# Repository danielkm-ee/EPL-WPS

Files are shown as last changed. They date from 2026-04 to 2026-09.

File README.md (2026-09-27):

# Spark EDM: An EDM power supply for hobby CNCs

A high-efficiency power supply unit designed for Electrical Discharge Machining (EDM) applications. The design is based on the Rack Robotics Powercore V3 and owes much to their engineering efforts.

## EPL Contributions

The EPL has reworked a few aspects of the Rack Robotics Powercore V3 for use in it's CNC-Type Wire EDM. Primarily, we've made use of 2.54mm pin headers in place of the spring-based connectors, or Pogo pins, to simplify construction without the enclosure. Other modifications have been made the the firmware project structure, separating sensor drivers, boost converter, fault handling, and other portions of the project into a modular C++ library. We have also implemented a frequency-coded feedback signal for compatibility with encoder and edge counting inputs available on many CNC control boards.

If you would like to explore or purchase the original PowerCore V3, please vist Rack Robotics at
The originial PowerCore V3 Repo
and
Rackrobo.io

# Repository Structure

```
├── docs               - documentation files & repository resources
│   ├── img                - images for README.md's
│   ├── LTSpice            - LTSpice Simulations
│   └── schematics         - pdfs of the schematics
├── firmware           - firmware project and library based on the PicoSDK
│   ├── docs               - docs for the firmware
│   ├── feedback_test      - firmware which outputs a frequency sweep for feedback testing
│   ├── src                - source files for the Spark EDM firmware
│   └── tpl0401b_test      - test firmware for testing the boost module potentiometer
├── hardware           - hardware resources for PCBs and the enclosure
│   ├── CAD                - CAD resources for enclosure design & system documentation
│   ├── circuit-boards     - circuit boards for the Spark EDM
│   └── KiCAD-library      - KiCAD library for the Spark EDM
└── tools              - tools for flashing & communicating with the Spark EDM
```

# Building the EDM Supply
The Spark EDM is not available for purchase through the EPL or any other means, but access to the manufacturing resources are provided for those with experience ordering and building up PCBs through the likes of JLCPCB, Oshpark, or PCBWay.

# LICENSE 
This project is based on Powercore V3 by Rack Robotics, Inc., used under CC BY-NC-SA 4.0.

Original copyright: © 2025 Rack Robotics, Inc.

Modifications and additions by Portland State University Electronics Prototyping Lab (PSU EPL) are also licensed under CC BY-NC-SA 4.0.

## Changes from Original
* Firmare:
    * Migration from Arduino to pure PicoSDK
    * new project structure and firmware documetation
    * frequency-coded feedback signal
    * testing firmware for the tpl10401b
    * tools for flashing and communicating with the device
    * extended command line interface with commands for setting the gap voltage and machining frequency
    * conventionalized responses from the serial interface for debugging
    * modularized library for the various functions of the power supply for extendability
    * fault handler and context management utilities
* Hardware:
    * Replacement of the RackRobotics and PowercoreV3 logo in compliance with copyright restrictions
    * Use of 2.54mm headers in place of spring-loaded connectors for ease of assembly
    * Removal of thermal reliefs on high-current capacitors in the pi-filter and boost converter module
    * Layout changes with larger trace widths for high current lines
    * Adaptations for 2.54mm connectors
    * Edge cutout for Pi Pico micro-USB and testpoints
    * Updated component values for missing JCL & digikey part numbers
* Documentation
    * Updated schematics reflecting changes in PCB implementation
    * Firmware documentation reflecting new library, developers manual, and coding conventions for maintenence and new feature introduction
    * Developer's notes from capstone members at Portland State University

## You are free to:
* Share — copy and redistribute the material in any medium or format
* Adapt — remix, transform, and build upon the material

### Under the following terms:
* **Attribution** — You must give appropriate credit, provide a link to the license, and indicate if changes were made
* **NonCommercial** — You may not use the material for commercial purposes
* **ShareAlike** — If you remix, transform, or build upon the material, you must distribute your contributions under the same license

For the full license text, see: https://creativecommons.org/licenses/by-nc-sa/4.0/

### Notices:
You do not have to comply with the license for elements of the material in the public domain or where your use is permitted by an applicable exception or limitation.

No warranties are given. The license may not give you all of the permissions necessary for your intended use. For example, other rights such as publicity, privacy, or moral rights may limit how you use the material.

For the full license text, see: https://creativecommons.org/licenses/by-nc-sa/4.0/

This includes all hardware designs, firmware, documentation, and associated files in this repository. Commercial use requires explicit written permission from the project maintainers.

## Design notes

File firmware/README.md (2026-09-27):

# Setup
This firmware is a pure C11 library against the Raspberry Pi Pico SDK.
No Arduino-Pico core is required.

## Toolchain (Fedora 43)
```bash
sudo dnf install arm-none-eabi-gcc-cs arm-none-eabi-gcc-cs-c++ \
                 arm-none-eabi-newlib cmake make libusb1-devel
```

## Pico SDK
Install the SDK anywhere; this project assumes `~/.local/share/pico-sdk`.
Initialise its submodules so TinyUSB (and friends) are present:
```bash
git clone https://github.com/raspberrypi/pico-sdk.git ~/.local/share/pico-sdk
cd ~/.local/share/pico-sdk && git submodule update --init
```

## picotool (USB flash + introspection)
The SDK's bundled picotool is built without USB support. Build a
standalone copy once:
```bash
git clone https://github.com/raspberrypi/picotool.git ~/.local/share/picotool-src
cd ~/.local/share/picotool-src && PICO_SDK_PATH=$HOME/.local/share/pico-sdk cmake -B build && make -C build -j
```

For non-root USB access, install the udev rule once:
```bash
sudo cp ~/.local/share/picotool-src/udev/60-picotool.rules /etc/udev/rules.d/
sudo udevadm control --reload && sudo udevadm trigger
```

## Build
```bash
cd firmware && mkdir build && cd build
PICO_SDK_PATH=$HOME/.local/share/pico-sdk cmake .. \
    -Dpicotool_DIR=$HOME/.local/share/picotool-src/install/lib/cmake/picotool
make -j
```
Artifacts land in `firmware/build/`: `epl_wps.elf`, `epl_wps.bin`,
`epl_wps.uf2`.

## Flash
With the Pico held in BOOTSEL (or already running compatible firmware
that exposes the picotool reset interface):
```bash
~/.local/share/picotool-src/build/picotool load -x firmware/build/epl_wps.uf2
```
`-x` reboots into the application after the load completes.

## Connect
The device exposes USB-CDC at `/dev/ttyACM0` (baud rate is irrelevant;
USB-CDC ignores it):
```bash
screen /dev/ttyACM0 115200      # or: minicom -D /dev/ttyACM0 -b 115200
```
Type `HELP` for the command listing, `HELP <cmd>` for usage of one.

# Command Interface
USB-CDC line interface, exact-match dispatch, strict argc validation,
`OK:` / `ERROR:` response prefixes:

| Command | Effect |
|---|---|
| `SEND_TELEMETRY` | Print the multi-line status block immediately |
| `SET_TELEMETRY <on/off>` | Enable or disable the periodic 1 Hz telemetry tick |
| `SET_ALL_PARAMETERS <discharges> <duty> <freq> <init_v>` | Validate against `config.h` SOA limits including computed on/off times, commit and clear `mode_prep_done` so the next OPERATING entry reconfigures PWM |
| `EDGE_DETECTION_MODE` / `EDM_ISOFREQUENCY_MODE` | Disable output stage, switch mode |
| `RESET_DEVICE` | Disable output stage, drain stdio, `watchdog_reboot(0,0,0)` |
| `SET_DPOT <pos>` | Direct DPOT write (development/diagnostic) |
| `READ_HVP_VOLTAGE` | Averaged read of boost output voltage |
| `UPDATE_DPOT_VOLTAGE_TABLE` | Re-run the startup voltage-table sweep |
| `SET_DPOT_FROM_VTABLE <volts>` | Ramp DPOT to closest table entry |
| `SET_FEEDBACK_RATIO <0..1>` | Directly set the EDM_FEEDBACK power ratio (encoded as PWM frequency) (development/diagnostic) |
| `HELP [<command>]` | List all commands, or print full usage for one |

Unknown commands print `ERROR: Unknown command 'X'` followed by the full
HELP listing.

# Theory of Operation

### Hardware overview
The Powercore is a two-phase EDM power supply:
- **High-voltage phase** ignites the discharge across the wire/workpiece gap. A boost-converter module produces 64–100 V DC, set by a TPL0401B digital potentiometer over I2C.
- **High-current phase** delivers the bulk discharge energy through a pi-filter module, drawing directly from the 48 V input (no programmable rail).
- Four MOSFETs are gated by RP2040 PWM: `SW_HIGH_VOLTAGE_PHASE_PIN` and `SW_HIGH_CURRENT_PHASE_PIN` are P-channel (inverted polarity); `SW_ENABLE_PIN` is N-channel; `OUTPUT_OVERCURRENT_SET_PIN` sets the comparator threshold.
- A motion controller (typically LinuxCNC) toggles `EDM_ENABLE_PIN` to request machining and reads back a power-ratio signal on `EDM_FEEDBACK_PIN`, encoded as PWM frequency at a fixed 50% duty cycle (200–400 Hz; see `docs/freq-encoding.md`).
- Three ADC channels: `PMM_ISENSE_PIN` (input current), `OUTPUT_VSENSE_PIN` (output voltage), `OUTPUT_ISENSE_PIN` (output current). Scaling constants live in `config.h`.
- Three fault sources: `PMM_FAULT_PIN`, `BOOST_PGOOD_PIN` (both active-low), `OUTPUT_OVERCURRENT_PIN` (comparator, falling edge).

### Architecture
```
main.c                                int main(void), boot sequence, main loop,
                                      single GPIO IRQ dispatcher
├── config.h                          pin map, hardware constants, SOA limits
└── src/
    ├── types.h                       device_state_t, mode_of_operation_t,
    │                                 fault_type_t, output_params_t, pwm_output_t
    ├── ctx.{h,c}                     main_ctx_t — central runtime state
    ├── sensors.{h,c}                 ADC, calibration, running average, conversions
    ├── pmm.{h,c}                     PMM enable + inrush wait, fault polling
    ├── boost.{h,c}                   DPOT I2C, voltage table, target-voltage ramp
    ├── output.{h,c}                  output-stage PWM + feedback + iso/edge mode bodies
    ├── fault.{h,c}                   pending/active fault, ISR entry points,
    │                                 main-loop dispatch
    └── cmd.{h,c}                     stdio_usb, command parser, telemetry block,
                                      static dispatch table
```

`main.c` owns three things: `g_ctx` (the runtime context), `g_boost_dpot`
(DPOT handle), and `g_boost_cal` (cal table). Every other module is a
singleton with file-static state inside its own `.c`. Cross-module
communication is by passing a `main_ctx_t *` pointer; only ISR-shared
fields are individually `volatile`. See `docs/library-reference.md` for
the full module-by-module API.

### Startup
`main()` brings USB-CDC up first so the rest of boot can log, then
initialises GPIOs, ADC, and the boost DPOT/I2C. It calibrates the
input-current zero offset with the PMM switch off, enables the PMM and
waits out inrush, then calibrates the output-current zero offset. It
registers the single system-wide GPIO IRQ callback and arms the
PMM-fault / boost-PGOOD / overcurrent edge IRQs, holds the HV-only
output stage active to sweep the DPOT and build a voltage cal table,
and trips `HIGH_VOLTAGE_PHASE_SETUP_FAULT` if that table failed to
build or measured above the safe ceiling. Boot ends in `IDLE` (or
`FAULT`, handled by the first main-loop iteration).

### Main loop
Each iteration: service any pending fault first (recoverable faults
block in a retry/recovery loop; non-recoverable ones require
`RESET_DEVICE`); poll for operator commands; run a ~100 Hz housekeeping
tick (input-current sampling, the `EDM_ENABLE_PIN` → state transition,
feedback-ratio update); dispatch the current state (`OPERATING` preps
the active mode lazily then runs its per-tick body, `IDLE` disables the
output stage); send periodic telemetry.

### Operating modes
- **EDM iso-frequency** — constant-frequency discharge generation. The
  output stage pulses the HV and HC phases out of phase to avoid
  shoot-through; each discharge event updates running current/voltage
  averages and a windowed success rate, which can pulse-skip the
  output if discharge success or input power runs too high.
- **Edge-detection** — single-pulse workpiece probing at a fixed low
  duty cycle. The first detected discharge disables the output
  immediately and signals the host with a feedback tone burst.

### Fault model
Three trip sources: PMM fault and boost-PGOOD loss are recoverable and
clear automatically once the condition resolves; HV-setup and
input-power faults are non-recoverable and require `RESET_DEVICE`.
`fault_trip()` always disables the output stage before raising the
pending flag, so the hardware is safe regardless of when the main loop
gets around to handling it.

---

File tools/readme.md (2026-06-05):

# Utilities for the WPS
Here is a place for tools and services built around the Wire Power Supply.

## wps-monitor.py
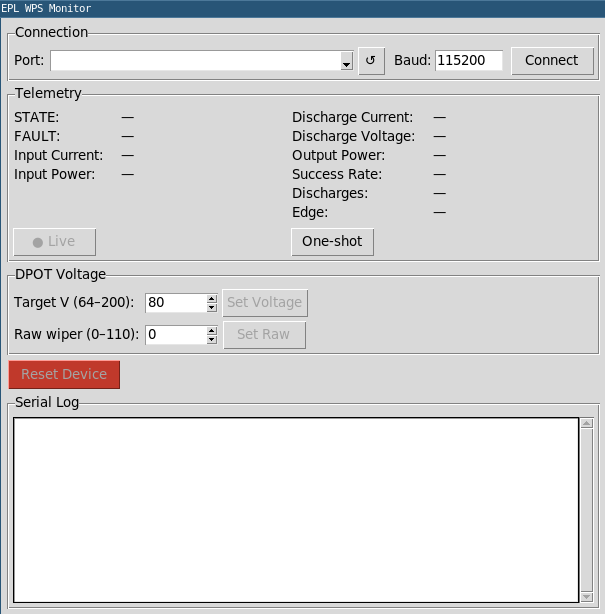
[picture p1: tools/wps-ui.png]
wps ui


This is a GUI for controlling viewing the Wire Power Supply. It includes a serial monitor and controls for setting the output voltage, resetting the device, and connecting to the device. 

> This has been developed in part using Claude 4.6

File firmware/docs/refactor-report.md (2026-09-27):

# Firmware Refactor Report

**Branch:** `firmware-refactor`
**Baseline:** `firmware.ino` — 1530 lines, single file, would not compile
**Result:** `firmware.ino` (336 lines) + 5 modules under `src/` (~900 lines total), clean compile at 74820 B flash / 10244 B RAM

**Goals:** make the firmware compile, fix latent runtime bugs, split into maintainable modules, and remove dead code from a prior hardware revision.

---

## Changelog

### Stage 1 — Bug fixes
- Fixed missing closing brace in `READ_HVP_VOLTAGE()` that caused the entire file to fail parsing
- Renamed `volatile FaultStateType FaultStateType` (variable shadowing its own type) to `currentFaultType`
- Fixed HV fault ISRs acknowledging `BOOST_CONVERTER_PGOOD_FAULT` (a fault enum value, not a GPIO) instead of `BOOST_PGOOD` (GPIO 18) — the interrupt was never actually cleared
- Fixed `sendTelemetry()` always printing `FAULT NONE` due to `isInFaultState` being declared but never assigned; replaced with `deviceState == FAULT`
- Moved all blocking work (`Serial.println`, `delay`, recovery loops) out of ISR context into `fault_handle()` on the main loop; ISRs now only ack the IRQ, disable the output stage, and set a pending flag

### Stage 2 — Extract shared headers
- `config.h`: all pin assignments, hardware constants, scaling factors, and safe-operating limits
- `src/types.h`: all shared enums and structs (`DeviceState`, `ModeOfOperation`, `FaultStateType`, `OutputParameters`, `PWMOutput`)

### Stage 3 — Split into modules

| Module | Responsibility |
|---|---|
| `sensors` | ADC setup, calibration, input-current averaging, ADC→engineering-unit conversions |
| `pwm_control` | EDM-feedback PWM and output-stage PWM setup, safe-OFF disable |
| `boost_module` | TPL0401B DPOT over I2C, voltage lookup table, `boost_set_voltage` ramping |
| `fault_handler` | Fault state, ISR registration, main-loop `fault_handle()` dispatcher |
| `telemetry` | Serial lifecycle, command parser, telemetry formatter, parameter validation |

### Stage 4 — Remove dead code (buck-converter era)
- Removed `BUCK_POWER_GOOD`, `BUCK_ENABLE`, `BUCK_ADJ_PWM` pin definitions and their `setup()` configuration (buck stage replaced by pi-filter board)
- Removed `BUCK_CONVERTER_PGOOD_FAULT` enum and its dead ISR
- Removed `PMM_FAULT_IN_USE`, `HIGH_CURRENT_PGOOD_IN_USE`, `HIGH_VOLTAGE_PGOOD_IN_USE` flags (all were compile-time constants); replaced conditional ISR registration with unconditional attaches
- Removed unused `pmm_recovered()` helper
- Removed duplicate `gpio_set_function(..., GPIO_FUNC_PWM)` calls
- Promoted two magic numbers to named `config.h` constants

### Stage 5 — Simplify state machine
- Removed `PERIPHERAL_MANAGEMENT` device state; periodic work is now an unconditional timed call from `loop()`
- Removed `oldDeviceState` shadow; post-fault recovery sets `deviceState = IDLE` and the next peripheral tick re-derives `OPERATING`/`IDLE` from `EDM_ENABLE`
- Removed global `currentFaultType`; owned internally by `fault_handler`, queried via `fault_current_type()`
- Inlined `enablePortStatus` global flag into a direct `digitalRead(EDM_ENABLE)` at the call site

---

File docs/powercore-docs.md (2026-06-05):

## Table of Contents

- [PSU HIGHLIGHTS](#psu-highlights)
- [FEATURES](#features)
- [APPLICATIONS](#applications)
- [GENERAL DESCRIPTION](#general-description)
- [SPECIFICATIONS](#specifications)
- [Recommended Operating Conditions](#recommended-operating-conditions)
- [DEVICE INTERFACES](#device-interfaces)
  - [Power Input Connector](#power-input-connector)
  - [Power Output Connector](#power-output-connector)
  - [Digital Interface Connector](#digital-interface-connector)
  - [USB-Micro Serial Interface](#usb-micro-serial-interface)
- [THEORY OF OPERATION](#theory-of-operation)
- [OPERATION MODES](#operation-modes)
  - [Startup Behavior](#startup-behavior)
  - [Idle Mode](#idle-mode)
  - [Iso-Frequency Mode](#iso-frequency-mode)
  - [Edge-Detection Mode](#edge-detection-mode)
- [APPLICATION EXAMPLE: MINIMUM IMPLEMENTATION](#application-example-minimum-implementation)
- [EMC & EMI](#emc--emi)
- [Images of PCBA](#images-of-pcba)
- [Typical PSU Waveforms](#typical-psu-waveforms)
- [LICENSE](#license)
- [⚠️ HIGH VOLTAGE SAFETY WARNING ⚠️](#️-high-voltage-safety-warning-️)

## PSU HIGHLIGHTS

1. Optimized for wire EDM applications
2. Maximum input power: 300W with high efficiency topology
3. Adjustable output parameters:
   - Machining Duty Cycle: 1% to 10%
   - Spark Initiation Voltage: 64V to 100V
   - Machining Frequency: 5kHz to 10kHz
4. USB serial interface for configuration and telemetry
5. PWM feedback output for external feedrate control
6. Edge detection capability for workpiece probing

Powercore V3 Enclosure View

## FEATURES

- **Dual-Converter Topology** with resonant converter and boost converter for high-efficiency EDM machining
- Input power optimized for desktop/micro-scale wire EDM (300W maximum, 48V input)
- Output parameters configurable via USB-micro serial interface
- Integrated protection features: pulse-skipping, overcurrent protection, and inrush protection
- Open-source electronics, firmware, and CAD files

## APPLICATIONS

- Wire EDM
- Plunge EDM
- Desktop-scale EDM machines
- Portable and battery-powered EDM machines
- Scientific research and development

## GENERAL DESCRIPTION

The Powercore V3 provides precision control of machining parameters including duty cycle, spark initiation voltage, and machining frequency. The system is optimized for desktop-scale wire EDM applications. The open-source design enables customization for research, development, and specialized EDM implementations.

## SPECIFICATIONS

| SPECIFICATION | Min | Max Value | UNIT |
| --- | --- | --- | --- |
| Average Input Power | 10 | 300 | W |
| Input Voltage | 47.8 | 48.2 | V |
| Input Current | 0.625 | 6.25 | A |
| Machining Duty Cycle | 1 | 10 | % |
| Spark Initiation Voltage | 64 | 100 | V |
| Machining Frequency | 5,000 | 10,000 | Hz |
| Machining Current (1) | 40 | 70 | A |
| PWM Feedback Duty Cycle | 0 | 100 | % |
| PWM Feedback Voltage | 0 | 3.3 | V |
| PWM Feedback Frequency  | — | 1,000 | Hz |
| PWM Feedback Output Impedance | 1,010 | 9,990 | Ω |
| Enable Input Voltage | 3.0 | 3.5 | V |
| Enable Input Impedance | 1,010 | 9,990 | Ω |

(1) Machining current depends on output cable impedance and discharge characteristics. Not regulated by constant-current control. Lower-impedance output cables provide higher machining current.

## Recommended Operating Conditions

| Parameter | Value |
| --- | --- |
| Ambient Temperature | 0°C to 30°C |
| Ingress Protection Rating | IP20 (Indoor use) |
| Relative Humidity | 20% to 80% (non-condensing) |
| Input Cable Gauge | 16 AWG minimum |
| Output Cable Gauge | 16 AWG stranded, 300V rated |
| Output Cable Length | <1 meter, twisted pair |
| Cooling | Forced air cooling recommended |

## DEVICE INTERFACES

Powercore V3 Device Interface Diagram

### POWER INPUT CONNECTOR

Input power connects via 2-position lever-action Wago connector accepting 16 AWG conductors. 48VDC input must be connected before applying 5V via USB-micro. If USB power is applied before 48VDC input, the microcontroller enters fault mode.

### POWER OUTPUT CONNECTOR 

Output connects via 2-position lever-action Wago connector accepting 16 AWG stranded conductors. Output cable must be twisted pair, <1 meter length, and either shielded/grounded or contained within a shielded/grounded enclosure.

### DIGITAL INTERFACE CONNECTOR 

4-position JST-XH header provides communication with external controllers. Exposes 3.3V and GND from RP2040 microcontroller with current-limiting resistors.

- **Enable Input**: Output is enabled when this input is connected to 3.3V or external 3.3V supply with common ground. 10kΩ pull-down resistor to GND.
- **Feedback Output**: Reports EDM power consumption via active-low PWM signal. 100% duty cycle indicates no power consumption from machining; 0% indicates short circuit. Maintain 10-90% duty cycle during machining by adjusting feedrate. 10kΩ pull-down resistor to GND. External low-pass filter can convert to analog feedback.

### USB-MICRO SERIAL INTERFACE

Exposes USB-micro connector of RP2040 Pico module for parameter configuration and telemetry. Default baud rate: 115,200.

**Warning**: Device requires both 48VDC input power AND 5V USB power. 48VDC must be connected first, or device enters fault mode.

| SERIAL COMMAND | DESCRIPTION |
| --- | --- |
| SEND_TELEMETRY | Request device status and parameters |
| SET_ALL_PARAMETERS | Configure machining parameters: discharges, duty cycle, frequency, initiation voltage<br>Format: 'SET_ALL_PARAMETERS [discharges] [duty_cycle] [frequency] [voltage]'<br>Example: 'SET_ALL_PARAMETERS 0 0.10 5000 100' |
| EDM_ISOFREQUENCY_MODE | Enter EDM iso-frequency mode |
| EDGE_DETECTION_MODE | Enter edge detection mode |
| RESET_DEVICE | Reset device |

Invalid commands return list of valid commands.

## THEORY OF OPERATION

The Powercore V3 generates controlled electrical discharges for EDM machining. The system cycles through spark initiation, current delivery, and discharge termination at high frequency (5-20kHz).

**Spark Initiation Voltage**: Determines spark formation conditions. Higher voltages create longer, more intense discharges suitable for harder materials.

**Machining Duty Cycle**: Controls discharge duration. Longer duty cycles increase material removal rate but may increase surface roughness.

**Machining Frequency**: Sets discharge repetition rate. Lower frequencies can increase material removal rate but may reduce surface finish quality.

**Machining Current**: Ranges from 40A to 70A, determined by fixed 48VDC output during current phase and combined impedance of output cables and discharge gap. Current is not user-adjustable.

## OPERATION MODES

### STARTUP BEHAVIOR 

On power-up, output is disabled (high-impedance state). Power management module initializes and pi-filter capacitors charge to 48V with inrush protection. Brief audible noise (~1 second) is normal during startup. Output current sensor calibrates and serial communication establishes.

**BOOST CONVERTER SELF-TEST**: System tests boost converter module and I2C digital potentiometer. If I2C communication fails, device reports 'ERROR: DPOT is not at expected position'. 

During startup, digital potentiometer cycles through settings 0-110, generating boost converter output voltage lookup table (50V-160V). If voltage range is insufficient, device enters fault mode and reports 'ERROR: DPOT voltage range is less than expected'.

Normal startup sequence via serial:
```
Setting DPOT to minimum position...
Waiting for voltage to stabilize...
Reading voltages for DPOT lookup table...
Boost Converter Digital Potentiometer Voltage Table:
0: 51
1: 52
...
109: 161
110: 166
```

Successful startup indicated by solid green LED and "Setup complete" message. Device enters IDLE mode.

### IDLE MODE

Output remains in high-impedance state until enable input is asserted (3.3V). No discharges occur in idle mode.

### ISO-FREQUENCY MODE

Fixed-frequency discharge mode. Default mode or activated via 'EDM_ISOFREQUENCY_MODE' command. Enable input must be asserted (3.3V) to begin operation.

**ISO-FREQUENCY MODE PARAMETERS**

| PARAMETER | Min | Default | Max | Unit |
| --- | --- | --- | --- | --- |
| Machining Duty Cycle | 1 | 10 | 10 | % |
| Machining Frequency | 5,000 | 1,000 | 10,000 | Hz |
| Spark Initiation Voltage | 64 | 80 | 100 | V |

### EDGE-DETECTION MODE

Probe mode for detecting electrode-workpiece contact via PWM feedback. Intended for setup and calibration only, not for machining. Activated via 'EDGE_DETECTION_MODE' command with enable input asserted.

## APPLICATION EXAMPLE: MINIMUM IMPLEMENTATION

Powercore V3 Minimum Implementation

Minimum system configuration:

| Connection | Requirements |
| --- | --- |
| Power Input | 48V, 300W supply via 16 AWG stranded wire |
| USB-Micro | 5V supply or PC connection. **Note**: 48V must be connected first |
| Enable Input | Connect to 3.3V after power supplies are connected |
| Power Output | Positive (+) to workpiece, negative (-) to electrode (wire/tool) |

## EMC & EMI

The Powercore V3 power supply unit is housed in a precision-machined, billet-aluminum enclosure, fully grounded to minimize electromagnetic interference. When no output cables are connected, radiated emissions are negligible. However, when output cables are attached, radiated emissions vary based on cable characteristics, including length, twist, and wire gauge.

**Requirements**: Output cables must be shielded, grounded, and twisted. Poor cable design may increase emissions and interfere with sensitive equipment.

**Installation**: Complete machining setup should be enclosed, shielded, and grounded. EMC compliance is installer's responsibility.

## Images of PCBA

### PCBA View 1
Powercore V3 PCBA View 1

### PCBA View 2
Powercore V3 PCBA View 2

### PCBA View 3
Powercore V3 PCBA View 3

### PCBA View 4
Powercore V3 PCBA View 4

## Typical PSU Waveforms

### Output Stage Switch Control
Normal behavior of output stage switches during EDM iso-frequency mode. The enable (yellow trace) and high-current phase (red trace) switches are both active at the same time, permitting current flow from the positive electrode to the negative electrode. The high-voltage switch is active several microseconds before each switching event, for the purpose of charging the output capacitor to the spark initiation voltage (blue trace).

Powercore V3 Waveform 1

### Gap Voltage with Electrodes Separated
Normal behavior of output stages during EDM iso-frequency mode, with the electrodes separated by several millimeters under distilled water. The positive (+) electrode (red trace) shows the change in gap voltage when the output capacitor is charged and then slowly discharged through the water.

Powercore V3 Waveform 2

### EDM Discharge Behavior
Normal behavior of output stages during EDM iso-frequency mode, during electrical discharge machining. The positive (+) electrode voltage changes rapidly during an EDM discharge; transitioning from the spark initiation voltage (here 80V) to the gap machining voltage (~40V) in several hundred nanoseconds.

Powercore V3 Waveform 3

Powercore V3 Waveform 4

### Boost Converter Operation
Normal behavior of the boost converter module. The MOSFET gate (blue trace) presents with short pulses, which are used to maintain a stable output voltage. The output voltage will be set by the I2C digital potentiometer to between 64 and 150 V.

Powercore V3 Waveform 5

Startup behavior of device. Two seconds are required for inrush protection and serial communication initiation. Subsequently, the boost converter and output voltage sensor collaborate to create the lookup table for the I2C digital potentiometer. Once the lookup table is constructed, the boost converter is set to its default 80V setting.

Powercore V3 Waveform 5

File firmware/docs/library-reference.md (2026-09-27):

# EPL Spark EDM Firmware — Library Reference

This document describes the modules under `firmware/src/` that together
implement the EPL Wire EDM Power Supply firmware. It is intended for a
developer who has just joined the project and wants to understand what
each module owns, how state is partitioned, and where to look when
adding a feature.

The firmware is **pure C11 against the Raspberry Pi Pico SDK**.

For setup, the build, the USB-CDC command table, and a short theory of
operation see `firmware/README.md` — this document does not repeat
that material. For the *why* behind the current shape see
`refactor-report.md`. For pin-level and electrical detail see
`config.h` and the schematics under `docs/schematics/`.

---

## 1. Architecture at a glance

```
            ┌───────────────────────────────────────────────┐
            │  main.c — boot sequence, main loop,           │
            │           single GPIO IRQ dispatcher          │
            └────────┬─────────────┬─────────────┬──────────┘
                     │             │             │
                     ▼             ▼             ▼
                 ┌───────┐    ┌────────┐    ┌────────┐
                 │  cmd  │    │ fault  │    │  ctx   │
                 │ (USB- │    │ (latch │    │ (state │
                 │  CDC) │◄───┤ + spin │    │  hub)  │
                 └───┬───┘    │  loop) │    └────────┘
                     │        └────┬───┘
                     │             │
                     └─────┬───────┘
                           ▼
                       ┌────────┐
                       │ output │  output-stage PWM,
                       │        │  feedback PWM,
                       │        │  iso / edge mode bodies,
                       │        │  overcurrent ISR
                       └───┬────┘
                           │
              ┌────────────┼────────────┐
              ▼            ▼            ▼
          ┌────────┐   ┌────────┐   ┌─────────┐
          │ boost  │   │  pmm   │   │ sensors │
          │ (DPOT/ │   │ (high- │   │  (ADC)  │
          │  I2C)  │   │  side) │   │         │
          └────────┘   └────────┘   └─────────┘

      shared types:        src/types.h
      hardware constants:  config.h
```

Three design rules drive the partitioning:

1. **`main.c` owns boot sequence, main loop, and the system-wide GPIO IRQ
   callback.** It is the only place that holds module-spanning runtime
   state (`g_ctx`, `g_boost_dpot`, `g_boost_cal`).
2. **Each `src/` module is a singleton with file-static state.** No
   transparent structs leak across module boundaries; ownership is
   one-peripheral-one-module. The `output` module is the only writer to
   the output-stage PWM slices; `boost` is the only thing that talks
   I2C to the DPOT; `sensors` is the only ADC consumer.
3. **Cross-module state lives in `main_ctx_t`** (defined in `ctx.h`) and
   is passed by pointer. No `extern` globals. ISR-shared fields are
   individually `volatile`.

Module APIs follow `module_func_desc()` naming. Constants are
`SCREAMING_SNAKE_CASE`. K&R braces.

---

## 2. Build layout

| File | Role |
|---|---|
| `main.c` | `int main(void)` — boot sequence, main loop, GPIO IRQ dispatcher. Owns `g_ctx`, `g_boost_dpot`, `g_boost_cal`. |
| `config.h` | Pin assignments (`*_PIN`), hardware constants, safe-operating limits, feature flags. **No runtime state.** |
| `CMakeLists.txt` | Pico SDK target definition, source list, link libs. |
| `src/types.h` | Shared enums (`device_state_t`, `mode_of_operation_t`, `fault_type_t`) and structs (`output_params_t`, `pwm_output_t`). |
| `src/ctx.{h,c}` | `main_ctx_t` and helpers (`ctx_init`, `ctx_set_state`, `ctx_set_mode`, `ctx_reset_discharge_stats`). |
| `src/sensors.{h,c}` | ADC drivers: PMM input current, output current, output voltage. Owns calibration offsets and the input-current running-average buffer. |
| `src/pmm.{h,c}` | Power-management module: high-side enable, inrush-wait, polled fault read. |
| `src/boost.{h,c}` | I2C driver for the boost-converter's TPL0401B digital potentiometer; owns the DPOT→voltage lookup table. |
| `src/output.{h,c}` | Phase-correct PWM for the four output-stage switches and the EDM_FEEDBACK signal; iso-frequency and edge-detection mode bodies; overcurrent ISR. |
| `src/fault.{h,c}` | ISR-thin / loop-thick fault model. Pending-fault flag, recovery dispatch, three ISR entry points. |
| `src/cmd.{h,c}` | USB-CDC stdio, command parser with static dispatch table, telemetry block. |

---

## 3. Shared types (`src/types.h`)

```c
typedef enum { STARTUP, FAULT, OPERATING, IDLE } device_state_t;

typedef enum { EDM_ISOFREQUENCY_MODE,
               EDGE_DETECTION_MODE } mode_of_operation_t;

typedef enum { PMM_FAULT_TYPE,
               BOOST_CONVERTER_PGOOD_FAULT,
               POWER_OUT_OF_RANGE_FAULT,
               HIGH_VOLTAGE_PHASE_SETUP_FAULT } fault_type_t;

typedef struct {
    int   discharge_count_target;   /* 0 = infinite */
    float duty_cycle;               /* 0.01 .. 0.12 */
    float frequency_hz;             /* 5000 .. 10000 */
    float init_voltage;             /* 64 .. 100 V */
} output_params_t;

typedef struct { uint32_t slice; uint32_t channel; } pwm_output_t;
```

`pwm_output_t` is shared so the output module can describe either of the
two channels (A/B) on a shared RP2040 PWM slice with the same descriptor.
`output_params_t` is the validated payload of `SET_ALL_PARAMETERS` and
the source of truth for live machining parameters (mirrored in
`main_ctx_t::params`).

---

## 4. Central runtime state — `main_ctx_t` (`src/ctx.h`)

```c
typedef struct {
    /* State machine */
    volatile device_state_t      state;
    volatile mode_of_operation_t mode;
    volatile bool                mode_prep_done;

    /* Machining parameters (mutated by SET_ALL_PARAMETERS) */
    volatile output_params_t     params;

    /* EDM iso-frequency discharge statistics (written by output ISR) */
    volatile bool     new_discharge_detected;
    volatile int      new_discharge_current_adc;
    volatile int      new_discharge_voltage_adc;
    volatile double   avg_discharge_current;
    volatile double   avg_discharge_voltage;
    volatile double   avg_discharge_success_rate;
    volatile double   discharge_success_rate;
    volatile int      current_discharge_count;
    volatile int      discharges_since_op_start;
    volatile bool     requested_discharges_reached;
    volatile uint32_t last_success_rate_calc_us;
    volatile int      discharge_rate_calc_interval_us;

    /* Edge-detection mode (written by output ISR) */
    volatile bool edge_detected;

    /* Periodic tick cursors (main loop only; not ISR-shared) */
    uint32_t last_periph_tick_ms;
    uint32_t last_telemetry_tick_ms;

    /* Feature flags (initialised from config.h constants) */
    bool allow_success_rate_pulse_skip;
    bool allow_power_setpoint_pulse_skip;
    bool periodic_telemetry_enabled;
} main_ctx_t;
```

`main.c` declares `static main_ctx_t g_ctx`. Every cross-module function
takes `main_ctx_t *ctx`. `volatile` is on the *fields* the ISRs touch,
not the pointer itself — passing a non-volatile pointer into ISR
context is intentional.

| Function | Effect |
|---|---|
| `ctx_init(ctx)` | Zero everything, set state=STARTUP, default machining params, copy feature flags from `config.h`. |
| `ctx_set_state(ctx, s)` | Direct state assignment. |
| `ctx_set_mode(ctx, m)` | Set mode and clear `mode_prep_done` so the next OPERATING entry re-preps. |
| `ctx_reset_discharge_stats(ctx)` | Clear all discharge-stat fields and `mode_prep_done`. Called by main loop after fault recovery. |

---

## 5. Module reference

### 5.1 `sensors` — ADC drivers

Owns three things:

- **Calibration offsets** for PMM input-current and output-current
  sensors. Captured at boot with no load on the sensor; subtracted from
  every subsequent ADC reading so 0 A reads as 0 A.
- **Input-current running-average buffer**
  (`DEVICE_CURRENT_BUFFER_SIZE = 100` samples). Filled by
  `sensors_sample_input_current()` once per peripheral-management tick
  (~10 ms) and read by the safety check and by telemetry.
- **Pure conversion helpers** for discharge ADC values captured inside
  the output-overcurrent ISR.

```c
void  sensors_init(void);
void  sensors_calibrate_input_current(void);   /* blocking, no-load */
void  sensors_calibrate_output_current(void);  /* blocking, no-load */

void  sensors_sample_input_current(void);
float sensors_avg_input_current_amps(void);
float sensors_read_output_voltage_averaged(int samples);

/* ISR fast paths */
int   sensors_read_output_current_adc(void);
int   sensors_read_output_voltage_adc(void);
float sensors_adc_to_discharge_current_amps(int adc);
float sensors_adc_to_discharge_voltage_volts(int adc);
```

ADC channel mapping is implicit in pin assignments: GPIO 26 = ADC0,
27 = ADC1, 28 = ADC2. Internally, every read does
`adc_select_input(pin - 26); adc_read()`.

Calibration order matters: PMM zero is taken with the high-side switch
*off*, then the switch is enabled and output-current zero is taken.
`main()` does this in the correct order.

### 5.2 `pmm` — power-management module switch

Three GPIOs control a separate board carrying a 48 V high-side switch
with built-in inrush limiting, overcurrent latch-off, and a diagnostic
fault output.

```c
void pmm_init(void);             /* directions, ENABLE deasserted, DIAG_EN asserted */
void pmm_enable_and_wait(void);  /* close the switch, sleep PMM_INRUSH_DELAY_MS */
void pmm_disable(void);
bool pmm_is_fault_active(void);  /* polled read; PMM_FAULT_PIN is active-low */
```

`PMM_FAULT_PIN`'s GPIO IRQ wiring is owned by the `fault` module + the
main.c dispatcher, not here.

### 5.3 `boost` — DPOT-driven HV rail

The boost converter's setpoint is controlled by a TPL0401B digital
potentiometer at I2C address `DPOT_ADDR` (0x3E). The module:

1. Initialises I2C0 (10 kHz, SDA=16, SCL=17).
2. Sweeps the DPOT 0..`BOOST_DPOT_POSITION_MAX` with the HV phase quietly
   enabled (no pulsing) and records the resulting rail voltage at each
   step into a `boost_cal_table_t`.
3. At runtime, translates a target voltage into the closest DPOT
   position via `boost_cal_lookup_wiper()` and ramps the wiper one
   position at a time so the rail rises smoothly.

```c
boost_dpot_t* boost_dpot_create(i2c_inst_t* port, uint8_t addr, uint8_t reg);
void          boost_setup_i2c  (boost_dpot_t* dpot, uint8_t sda, uint8_t scl, uint16_t baud);

void    boost_dpot_write_position(boost_dpot_t*, uint8_t pos);
uint8_t boost_dpot_read_position (boost_dpot_t*);
uint8_t boost_dpot_clamp_position(uint8_t pos);
float   boost_dpot_get_voltage   (const boost_dpot_t*, const boost_cal_table_t*);

boost_cal_status_t boost_cal_build(boost_dpot_t*, boost_cal_table_t*,
                                   int adc_samples, uint32_t settle_ms);
uint8_t            boost_cal_lookup_wiper(const boost_cal_table_t*, float target_v);
void               boost_set_voltage     (boost_dpot_t*, const boost_cal_table_t*,
                                          float target_v, uint32_t ramp_step_ms);
```

The lookup table is rebuilt on demand by `UPDATE_DPOT_VOLTAGE_TABLE`.
Failure leaves `cal->calibrated == false`; `main.c::verify_boost_cal_safe`
trips `HIGH_VOLTAGE_PHASE_SETUP_FAULT` if either the table never built
or its max measured voltage exceeded `MAX_HIGH_VOLTAGE_PHASE_VOLTS`.

### 5.4 `output` — output stage and mode bodies

The largest module: it absorbs the original `pwm_control` plus the
EDM iso-frequency / edge-detection state-machine bodies.

Drives five PWM channels across three slices:

| Pin | Slice/Ch | Polarity | Purpose |
|---|---|---|---|
| `SW_HIGH_VOLTAGE_PHASE_PIN` (8)  | 4A | inverted (P-ch) | HV pulse switch |
| `OUTPUT_OVERCURRENT_SET_PIN` (9) | 4B | normal | Comparator threshold (PWM-as-DAC) |
| `SW_ENABLE_PIN` (10) | 5A | normal (N-ch) | Output stage enable |
| `SW_HIGH_CURRENT_PHASE_PIN` (11) | 5B | inverted (P-ch) | HC pulse switch |
| `EDM_FEEDBACK_PIN` (3) | 1B | normal | Power-ratio out to motion controller (frequency-encoded) |

```c
/* Lifecycle */
void output_init(void);
void output_attach_isr(main_ctx_t *ctx);
void output_overcurrent_isr(void);              /* called only by main.c dispatch */

/* Feedback PWM (motion-controller signal): power ratio is encoded as
 * PWM frequency at a fixed duty (EDM_FEEDBACK_PWM_DUTY). */
void output_feedback_set_ratio(float ratio);   /* 0..1 -> MIN..MAX freq */
void output_feedback_disable(void);            /* PWM off, line low */

/* Output stage */
void output_stage_setup(float duty, int freq_hz, float oc_threshold_a,
                        bool enable_main_slice, bool enable_hv_slice,
                        float hv_pulse_us, float hv_offset);
void output_stage_disable(void);

/* Mode entry (validates cal->calibrated; caller ramps boost first) */
bool output_setup_isofreq(main_ctx_t *ctx, const boost_cal_table_t *cal);
bool output_setup_edge   (const boost_cal_table_t *cal);

/* Per-tick mode bodies */
void output_run_isofreq(main_ctx_t *ctx);
void output_run_edge   (main_ctx_t *ctx);
```

Things that are easy to get wrong and therefore worth knowing:

1. **Phase-correct counter.** The output-stage slices use up-down
   counting, which doubles the period:
   `wrap = PWM_BASE_CLOCK_FREQ / (frequency_hz * 2)`.
2. **HV-phase counter offset.** The HV slice's counter is started at
   `wrap * EDM_ISOFREQ_HV_PWM_OFFSET` (currently 0.25) so the HV pulse
   and the HC pulse cannot overlap, preventing shoot-through between
   the two output switches.
3. **Slice grouping.** `SW_ENABLE_PIN` and `SW_HIGH_CURRENT_PHASE_PIN`
   share PWM slice 5; they cannot be enabled independently. Likewise
   `SW_HIGH_VOLTAGE_PHASE_PIN` and `OUTPUT_OVERCURRENT_SET_PIN` share
   slice 4. Hence the two enable booleans (`enable_main_slice`,
   `enable_hv_slice`) on `output_stage_setup`.
4. **P-channel inversion.** `pwm_set_output_polarity()` inverts the
   affected channels at the slice level. `output_stage_disable()` then
   bypasses PWM entirely and drives each gate to its safe-OFF level by
   hand: it reclaims each pad as `GPIO_FUNC_SIO` (without this the PWM
   peripheral still owns the pad and `gpio_put` is a no-op), then
   drives N-ch LOW and P-ch HIGH.
5. **Boost coupling.** `output_setup_isofreq` / `output_setup_edge` do
   *not* ramp the boost DPOT. The caller (main.c) must invoke
   `boost_set_voltage()` first; these functions only validate that the
   cal table is calibrated.
6. **Pulse-skip auto-rearm.** When iso-frequency mode triggers a
   pulse-skip pause, an internal helper re-arms the PWM slices with the
   current params after the pause. The original Arduino-era code
   disabled but never re-enabled, leaving the output dead until the
   next IDLE cycle.

`output_overcurrent_isr()` is the discharge-event handler:

- **Iso-freq:** snapshots `sensors_read_output_current_adc/voltage_adc`,
  bumps `ctx->current_discharge_count` and
  `ctx->discharges_since_op_start`, sets
  `ctx->new_discharge_detected`. Pure flag-set; no I/O.
- **Edge:** if `ctx->edge_detected` is unset, latches it and calls
  `output_stage_disable()` immediately. The main-loop body handles the
  signaling protocol.

### 5.5 `fault` — ISR-thin, loop-thick

Three sources, four types:

```c
void         fault_init(void);
void         fault_attach_irqs(void);

bool         fault_pending(void);
fault_type_t fault_active_type(void);
const char  *fault_type_name(fault_type_t);

void         fault_trip(fault_type_t type);              /* ISR-safe */
void         fault_handle(main_ctx_t *ctx,
                          bool (*cmd_poll_fn)(main_ctx_t *));

void         fault_pmm_isr(void);
void         fault_boost_pgood_isr(void);
```

The contract:

- **`fault_trip(type)` is universally safe.** It immediately calls
  `output_stage_disable()`, sets the active fault type, and raises the
  pending flag. ISRs call it; in-line detectors call it; the main-loop
  power-out-of-range check calls it.
- **`fault_handle()` runs only on the main loop.** It prints the fault
  name, defensively re-disables the output stage and clears the
  feedback duty, then dispatches by type:
  - `PMM_FAULT_TYPE` — 500 ms LED-off pause, recover.
  - `BOOST_CONVERTER_PGOOD_FAULT` — `fault_spin_until(boost_recovered)`.
  - `POWER_OUT_OF_RANGE_FAULT` / `HIGH_VOLTAGE_PHASE_SETUP_FAULT` —
    `fault_spin_until(NULL)`. Operator must `RESET_DEVICE`.
- **`cmd_poll_fn` is a function pointer** so the recovery spin can
  service operator commands without `fault.h` having to include
  `cmd.h`. `main.c` passes `cmd_poll`. NULL is allowed but disables
  operator interaction during recovery.

The two ISR entry points (`fault_pmm_isr`, `fault_boost_pgood_isr`)
are called only from the GPIO dispatcher in `main.c`. They are
one-liners that just call `fault_trip()` with the appropriate type.

The output-overcurrent ISR is in `output.c`, not here, because its
behaviour is mode-dependent.

### 5.6 `cmd` — USB-CDC command surface

Two halves:

- **Inbound (`cmd_poll`)** — non-blocking. Drains pending stdio bytes
  via `getchar_timeout_us(0)`, accumulates a 128-byte line, and on
  newline tokenizes via `strtok_r` and dispatches against a static
  table.
- **Outbound (`cmd_send_telemetry`)** — multi-line status block
  (firmware version, state, fault, input current/power, mode-specific
  stats and parameters). Called once per second from `cmd_tick` and
  on demand via the `SEND_TELEMETRY` command.

```c
void cmd_init(void);                                  /* stdio_init_all + 1s enum wait */
void cmd_set_boost_ctx(boost_dpot_t*, boost_cal_table_t*);  /* one-shot DI */
bool cmd_poll(main_ctx_t *ctx);                       /* non-blocking; dispatch one line */
void cmd_tick(main_ctx_t *ctx);                       /* periodic telemetry @ 1 Hz */
void cmd_send_telemetry(const main_ctx_t *ctx);
```

The dispatch table entry type lives in `cmd.c`:

```c
typedef struct {
    const char     *name;        /* exact-match keyword */
    int             argc_min;    /* required arg count, lower bound */
    int             argc_max;    /* required arg count, upper bound */
    cmd_handler_fn  handler;     /* called only after name + argc match */
    const char     *usage;       /* one-line syntax */
    const char     *desc;        /* one-line description for HELP */
} cmd_entry_t;
```

Dispatch rules:

- Names are matched **exactly** (no `startsWith` / prefix match).
- `argc` is checked against `[argc_min, argc_max]` before the handler
  is called; mismatches print the usage line and abort.
- Unknown commands print `ERROR: Unknown command 'X'` followed by the
  full HELP listing.
- All status/error messages use `OK: ...` / `ERROR: ...` prefixes.
- `HELP` (no args) prints the full listing; `HELP <CMD>` prints the
  usage and description for one entry.

See `firmware/README.md` for the current command table. The table is
maintained by hand alongside `g_cmd_table[]` — keep both in sync when
adding a command.

#### Adding a new command

Everything lives in `cmd.c`; no other module needs to change unless
the command touches new state.

1. **Forward-declare and implement a static handler** matching
   `cmd_handler_fn`:
   ```c
   static void cmd_handle_my_command(int argc, char **argv, main_ctx_t *ctx);
   ```
   `argv[0]` is the command name itself; `argv[1..]` are the
   already-tokenized arguments. Print `OK: ...` on success or
   `ERROR: ...` on failure — there is no other return channel. Example
   (the real `SET_TELEMETRY` handler):
   ```c
   static void cmd_handle_set_telemetry(int argc, char **argv, main_ctx_t *ctx)
   {
       (void)argc;
       if (strcmp(argv[1], "on") == 0 || strcmp(argv[1], "ON") == 0) {
           ctx->periodic_telemetry_enabled = true;
           printf("OK: Periodic telemetry ON\n");
       } else {
           ctx->periodic_telemetry_enabled = false;
           printf("OK: Periodic telemetry OFF\n");
       }
   }
   ```
2. **Add a row to `g_cmd_table[]`**, before the `{ NULL, ... }`
   sentinel:
   ```c
   { "SET_TELEMETRY", 1, 1, cmd_handle_set_telemetry,
     "SET_TELEMETRY <on/off>",
     "Enable or disable telemetry updates." },
   ```
   `argc_min`/`argc_max` count arguments **excluding** the command name
   (`cmd_dispatch` checks `argc - 1` against this range). Use equal
   `min`/`max` for a fixed arg count, or a range for optional args (see
   `HELP`'s `0, 1`).
3. **Add the row to the table in `README.md`** by hand — it is not
   generated from `g_cmd_table[]`.

That's the whole surface: `cmd_lookup`, `cmd_dispatch`, the strict-argc
check, and `HELP`/`cmd_print_listing` all key off `g_cmd_table[]`
automatically, so a new entry is picked up with no other wiring. The
one exception is a command needing more than `MAX_CMD_PARAMS` (4)
arguments — that constant (`config.h`) sizes the tokenizer's fixed
`argv` array and would need to grow first.

Validation in `apply_parameters()` is the only path through which the
device's output behaviour changes via serial. It validates against
`MIN_/MAX_DUTY_CYCLE`, `MIN_/MAX_MACHINING_FREQUENCY_HZ`,
`MIN_/MAX_INIT_VOLTAGE`, computed on-time within
`MIN_/MAX_ON_TIME_MICROS`, and computed off-time at least
`MIN_OFF_TIME_MICROS`. On success it sets `ctx->mode_prep_done = false`
so the next OPERATING entry re-applies the new values.

---

## 6. Lifecycle

### 6.1 Boot (`int main(void)`)

1. `ctx_init(&g_ctx)`.
2. `cmd_init()` — `stdio_init_all` + 1 s USB-CDC enumeration delay; print
   `Software Version: rev0`.
3. STATUS LED + EDM_ENABLE GPIO directions.
4. `output_init()` — cache PWM slice/channel descriptors, configure
   feedback PWM, force the four output switches into safe-OFF SIO state.
5. `pmm_init()` — directions, ENABLE deasserted, DIAG_EN asserted.
6. `sensors_init()` — `adc_init` + `adc_gpio_init` for the three sensor
   pins.
7. `boost_dpot_create` + `boost_setup_i2c`; `cmd_set_boost_ctx()` injects
   the dpot and cal table into the cmd module.
8. `sensors_calibrate_input_current()` — PMM zero with switch off.
9. `pmm_enable_and_wait()` — close the high-side switch, sleep
   `PMM_INRUSH_DELAY_MS`.
10. `sensors_calibrate_output_current()` — output-side zero now that the
    bus is alive.
11. `gpio_set_irq_callback(gpio_irq_dispatch); irq_set_enabled(IO_IRQ_BANK0, true)`
    — register the system-wide GPIO callback **once**. Per-pin enables
    in `fault_attach_irqs` and `output_attach_isr` use the no-callback
    variant and attach to this dispatcher.
12. `fault_init() + fault_attach_irqs()` — arms PMM_FAULT and BOOST_PGOOD
    edge IRQs.
13. `output_attach_isr(&g_ctx)` — binds ctx, arms OUTPUT_OVERCURRENT.
14. **HV-only output stage** brought up so the boost can be characterised.
15. `boost_cal_build(g_boost_dpot, &g_boost_cal, 8, 20)`.
16. `verify_boost_cal_safe()` — trips `HIGH_VOLTAGE_PHASE_SETUP_FAULT` if
    the cal table never built or its max measured voltage exceeds
    `MAX_HIGH_VOLTAGE_PHASE_VOLTS`.
17. `output_stage_disable()`.
18. If a fault is pending, print "ERROR: setup failed; fault pending"
    and let iteration 1 of the main loop dispatch it. Otherwise
    STATUS_LED on, "OK: Setup complete", state → IDLE.

### 6.2 Main loop

```c
while (1) {
    uint32_t now_ms = to_ms_since_boot(get_absolute_time());

    if (fault_pending()) {                    // (1) faults take priority
        ctx_set_state(&g_ctx, FAULT);
        fault_handle(&g_ctx, cmd_poll);
        ctx_reset_discharge_stats(&g_ctx);
        ctx_set_state(&g_ctx, IDLE);
        continue;
    }

    cmd_poll(&g_ctx);                         // (2) commands every iteration

    if (now_ms - g_ctx.last_periph_tick_ms    // (3) housekeeping @ 100 Hz
        >= PERIPH_MGMT_INTERVAL_MS) {
        periph_tick();                        //     PMM sample,
        g_ctx.last_periph_tick_ms = now_ms;   //     power envelope,
    }                                         //     EDM_ENABLE → state,
                                              //     feedback duty
    switch (g_ctx.state) {                    // (4) state body
    case OPERATING:
        if (!g_ctx.mode_prep_done)
            prepare_isofreq_mode() / prepare_edge_mode();
        if (g_ctx.mode_prep_done)
            output_run_isofreq() / output_run_edge();
        break;
    case IDLE:
        output_stage_disable();
        g_ctx.mode_prep_done = false;
        g_ctx.discharges_since_op_start = 0;
        sleep_ms(10);
        break;
    case STARTUP:
    case FAULT:
        break;
    }

    cmd_tick(&g_ctx);                         // (5) telemetry @ 1 Hz
}
```

Order matters:

- **Faults first.** Recovery may run for a long time; nothing else
  should attempt to re-arm hardware while a fault is pending.
- **`cmd_poll` every iteration.** No periodic gating — operators get
  prompt response. Latency is whatever the slowest iteration takes
  (`sleep_ms(10)` in IDLE, much shorter in OPERATING).
- **Periph tick at 100 Hz.** Polls EDM_ENABLE_PIN to drive the
  IDLE↔OPERATING transition, watchdogs the input-power envelope, and
  keeps the feedback signal in sync with measured input current.
- **Mode prep at OPERATING entry.** `prepare_isofreq_mode` /
  `prepare_edge_mode` ramp the boost (`boost_set_voltage`) and call the
  matching `output_setup_*`. `mode_prep_done` is only latched true if
  prep didn't trip a fault.

### 6.3 GPIO IRQ wiring

The RP2040 SDK only allows **one system-wide GPIO IRQ callback**. Every
edge-triggered pin in this firmware (`PMM_FAULT_PIN`, `BOOST_PGOOD_PIN`,
`OUTPUT_OVERCURRENT_PIN`) routes through `gpio_irq_dispatch` in
`main.c`, which dispatches by pin to one of:

```
fault_pmm_isr()         ← PMM_FAULT_PIN falling edge
fault_boost_pgood_isr() ← BOOST_PGOOD_PIN falling edge
output_overcurrent_isr()← OUTPUT_OVERCURRENT_PIN falling edge
```

Modules expose these `_isr` entry points but do not register them with
the SDK. The default GPIO callback dispatcher acknowledges edge IRQs
automatically; ISRs do not need to call `gpio_acknowledge_irq`.

### 6.4 Operating modes

**EDM iso-frequency** (`output_run_isofreq`):

- Drains `ctx->new_discharge_detected` flag set by the ISR; folds I/V
  ADCs through `sensors_adc_to_discharge_*` and into 0.9/0.1 EWMAs.
- At each calc-window boundary (every `DISCHARGES_PER_CALC_INTERVAL`
  discharges or `discharge_rate_calc_interval_us`, whichever first),
  recomputes `discharge_success_rate` and the 0.99/0.01 EWMA
  `avg_discharge_success_rate`.
- Two pulse-skip guards (gated by `ctx->allow_*_pulse_skip`):
  - Success rate ≥ `MAX_DISCHARGE_SUCCESS_RATE_THRESHOLD` (0.8) →
    disable, 250 ms wait, re-arm.
  - Avg input power > `MAX_INPUT_POWER_SETPOINT_WATTS` (75 W) →
    disable, 10 ms wait, re-arm.
- Honours `params.discharge_count_target` (0 = infinite). Latches
  `requested_discharges_reached` when reached.

**Edge detection** (`output_run_edge`):

- Drains `ctx->edge_detected` (latched by the ISR with the output
  already disabled).
- Drives feedback to `EDM_FEEDBACK_FREQ_MAX_HZ` (tone burst) for 1 s,
  then disables the feedback PWM (silence) for 1 s, then clears the
  flag. After detection the output stays disabled until the device
  cycles through IDLE.

---

## 7. Conventions for new code

When adding to this codebase:

- **Hardware constants and tunables go in `config.h`.** No runtime
  state in `config.h`.
- **Shared enums or structs go in `src/types.h`.** Module-private types
  stay module-private (file-static or in the `.c`).
- **Cross-module state goes in `main_ctx_t`** (`ctx.h`). ISR-shared
  fields must be individually `volatile`.
- **One peripheral, one module.** If you find yourself touching ADC
  pins outside `sensors.c`, PWM slices outside `output.c`, or I2C
  outside `boost.c`, move it.
- **Every header is `extern "C"` guarded** — `#ifdef __cplusplus`
  / `extern "C" {`.
- **Functions that may be called from an ISR must be ISR-safe** — no
  `printf`, no `sleep_ms`, no I2C. Pattern: ISR sets a flag (or pushes
  ADC samples into volatile state), main loop consumes.
- **New fault sources:** extend `fault_type_t` in `types.h`, add a
  `_isr` entry point in `fault.c` (or wherever the pin lives), add a
  case to `fault_handle()` so the recovery semantics are explicit, and
  a branch in `gpio_irq_dispatch()` if the source is a new GPIO.
- **New commands:** add a `cmd_handle_*` static handler in `cmd.c`, an
  entry in the `g_cmd_table[]` with `[argc_min, argc_max]`, `usage`,
  and `desc`. The strict-argc dispatcher will validate before invoking
  the handler.
- **Pin constants:** all pin numbers in `config.h` carry a `_PIN`
  suffix.
- **Naming:** `module_func_desc()`. Constants `SCREAMING_SNAKE_CASE`.
  K&R braces. Use `float` for sensor conversions (not `double`) unless
  there is a specific accuracy reason to widen.

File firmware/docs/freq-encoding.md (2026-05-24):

# EDM_FEEDBACK frequency encoding

The `EDM_FEEDBACK` line carries the powercore's instantaneous
input-power-draw ratio to the motion controller, encoded as PWM
frequency at a fixed 50% duty cycle. This document covers:

- what value goes on the wire
- how and how often the firmware updates it
- a LinuxCNC HAL prototype for converting it back into a 0..1 control
  variable on a Mesa 7i76e

## What's on the wire

The transmitted scalar is the **input-power ratio**:

    ratio = (avg_input_current * INPUT_SUPPLY_VOLTAGE)
            / MAX_INPUT_POWER_SETPOINT_WATTS

i.e. the averaged 48 V-rail current draw normalised against the 75 W
thermal/SOA setpoint. It is a proxy for sparking intensity:

| ratio | interpretation |
|---|---|
| → 0 | little or no current — wire too far from work, no sparking |
| → 1 | drawing at the SOA limit — gap shorted or arcing |

This is *correlated with* but not identical to discharge success rate
(the fraction of attempted pulses that successfully fire). Success
rate is computed inside the firmware as
`ctx->avg_discharge_success_rate` (`src/output.c` per-tick body) but
is not currently transmitted. Swapping the source is a one-line
change in `periph_tick()` if a more direct gap-condition measurement
is wanted later.

## Source measurement (firmware-side)

ADC sampling lives in `src/sensors.c`:

- `sensors_sample_input_current()` (`sensors.c:71-81`) takes one PMM
  current-sense ADC sample, converts to amps, pushes it into a
  100-deep ring buffer.
- `sensors_avg_input_current_amps()` (`sensors.c:83-92`) returns the
  buffer mean.

At the 100 Hz sample rate (next section), the buffer represents a
~1-second moving average once full. That averaging window is the
dominant smoothing term in the whole feedback path.

## Update cadence

`periph_tick()` in `main.c:129-150` is the only writer of the
feedback PWM. It is invoked from the main loop's gated 100 Hz cadence
(`PERIPH_MGMT_INTERVAL_MS = 10` ms). Each tick:

1. `sensors_sample_input_current()` — one new sample into the ring.
2. `MAX_SAFE_INPUT_CURRENT` envelope check.
3. State decision from `EDM_ENABLE_PIN`.
4. `output_feedback_set_ratio(ratio)` if OPERATING, otherwise
   `output_feedback_disable()`. This is where the PWM frequency is
   reprogrammed (`pwm_set_wrap` + `pwm_set_chan_level`).

So: **the feedback PWM frequency is reprogrammed every 10 ms** while
OPERATING.

## Encoding

Constants live in `config.h`:

    EDM_FEEDBACK_FREQ_MIN_HZ        = 200    # ratio = 0 -> 200 Hz
    EDM_FEEDBACK_FREQ_MAX_HZ        = 400    # ratio = 1 -> 400 Hz
    EDM_FEEDBACK_PWM_DUTY           = 0.5
    EDM_FEEDBACK_PWM_CLOCK_DIVIDER  = 64

Mapping is linear and non-inverted; computed inside
`output_feedback_set_ratio()` (`src/output.c`):

    freq_hz = MIN + ratio * (MAX - MIN)
    wrap    = PWM_BASE_CLOCK_FREQ / (freq_hz * CLOCK_DIVIDER)
    level   = wrap * DUTY

The 200–400 Hz range is chosen for responsiveness rather than
resolution. At 200 Hz the period is 5 ms — half the 10 ms firmware
update interval — so the host sees at least two full cycles between
updates. A wider range (e.g. 50–500 Hz) gives more dynamic range,
but at the low end the cycle period would exceed the update
interval, smearing each new value across multiple host servo-thread
reads before the next update lands.

Practical resolution on the host side is roughly 200 Hz of range
quantised to integer Hz, so ~200 distinct steps over the ratio range.
Adequate for feedrate-scaling; not adequate for tight precision
control.

## Edge cases

- **IDLE / fault / boot**: `output_feedback_disable()` halts the PWM
  and the line idles low (no edges). The host should treat "no
  signal" distinctly from "ratio = 0" — either gate adaptive feed on
  the `EDM_ENABLE` line or rely on HostMot2's `vel-timeout`.
- **EDGE_DETECTION_MODE signaling**: when an edge is detected the
  feedback PWM is driven to `EDM_FEEDBACK_FREQ_MAX_HZ` for 1 s, then
  disabled for 1 s. The motion controller can detect this as a tone
  burst followed by silence — distinguishable from any normal
  in-range ratio.

## LinuxCNC HAL prototype (Mesa 7i76e)

The 7i76e daughtercard's encoder counter, configured for
single-channel edge counting, exposes raw Hz on its `velocity` pin.
Wire `EDM_FEEDBACK_PIN` to the A input of one encoder channel.

Component names and indices in this snippet are illustrative — match
to your actual bitfile and board enumeration.

```hal
# --- 1. Read frequency off the encoder counter -----------------------
setp hm2_5i25.0.encoder.00.counter-mode  1     # single-channel edge count
setp hm2_5i25.0.encoder.00.scale         1     # velocity in raw Hz
setp hm2_5i25.0.encoder.00.vel-timeout   0.05  # zero out below ~20 Hz

net edm-fb-hz <= hm2_5i25.0.encoder.00.velocity

# --- 2. Map Hz back to ratio in [0,1] --------------------------------
# ratio = (hz - FMIN) / (FMAX - FMIN)
# With FMIN=200, FMAX=400: gain = 1/200 = 0.005, offset = -200/200 = -1.0
loadrt scale  names=fb_to_ratio
loadrt limit2 names=fb_clamp
addf fb_to_ratio servo-thread
addf fb_clamp    servo-thread

setp fb_to_ratio.gain    0.005
setp fb_to_ratio.offset -1.0
setp fb_clamp.min        0.0
setp fb_clamp.max        1.0

net edm-fb-hz     => fb_to_ratio.in
net edm-ratio-raw <= fb_to_ratio.out
net edm-ratio-raw => fb_clamp.in
net edm-ratio     <= fb_clamp.out      # <-- 0..1 control variable

# --- 3. Drive feedrate from the ratio --------------------------------
# Option A: dumb linear map. ratio 0 -> full feed, ratio 1 -> 20% feed.
loadrt scale names=ratio_to_feed
addf ratio_to_feed servo-thread
setp ratio_to_feed.gain   -0.8
setp ratio_to_feed.offset  1.0
net edm-ratio     => ratio_to_feed.in
net adaptive-feed <= ratio_to_feed.out
net adaptive-feed => motion.adaptive-feed
setp motion.adaptive-feed-enable 1

# Option B (recommended once tuning starts): PID toward a setpoint
# (e.g. ratio = 0.5 as the sparking sweet spot).
# loadrt pid names=edm_pid
# addf  edm_pid.do-pid-calcs servo-thread
# setp  edm_pid.Pgain      1.0
# setp  edm_pid.Igain      0.2
# setp  edm_pid.maxoutput  0.5    # never boost feed by >50%
# setp  edm_pid.minoutput -0.8    # allow large slowdowns
# net edm-setpoint => edm_pid.command       # constant 0.5 from a setp
# net edm-ratio    => edm_pid.feedback
# net feed-trim    <= edm_pid.output
# ... sum2 with 1.0 nominal, into motion.adaptive-feed
```

### Notes for the host integrator

- **Quantization at the band edges.** With `vel-timeout = 50 ms`, the
  HostMot2 estimator sees ~10 cycles at 200 Hz and ~20 at 400 Hz per
  window — enough for a stable velocity estimate. Shortening the
  timeout reduces latency but raises noise; lengthening it does the
  opposite. A `lowpass` on `edm-ratio` is a good knob to expose.
- **IDLE handling.** When firmware calls `output_feedback_disable()`
  the line is silent and `vel-timeout` will zero the velocity, which
  the linear-map Option A interprets as "full feed." Either gate
  `motion.adaptive-feed-enable` off the `EDM_ENABLE` electrical
  counterpart or use a `mux2` to substitute a safe value when the
  enable line is low.
- **Edge-mode signaling.** The 1 s `MAX_HZ` tone followed by 1 s of
  silence at the start of edge detection will be visible on
  `edm-ratio` as a brief ramp to 1.0 then 0.0. If the motion
  controller is going to act on this it needs its own debounce — a
  spurious ratio = 1 sample inside the tone burst would trigger
  Option A's slowdown.

## Latency budget

End-to-end response from "input current changes" to "motion
controller acts":

| stage | typical |
|---|---|
| ADC sample → ring buffer push | < 1 ms |
| 1 s moving-average smoothing | up to 1 s (dominant) |
| Firmware tick → PWM reprogram | up to 10 ms |
| 1–2 PWM cycles on the wire | 2.5–10 ms |
| HostMot2 velocity estimate | ~1 servo period (1 ms) |
| HAL chain (scale + clamp + feedrate) | ~1 ms per addf |

The 1 s ring-buffer average is by far the dominant smoothing term;
the wire-and-host transport adds ~15–25 ms of worst-case delay on top
of that. Tighten the average via `DEVICE_CURRENT_BUFFER_SIZE` if the
control loop needs faster response.

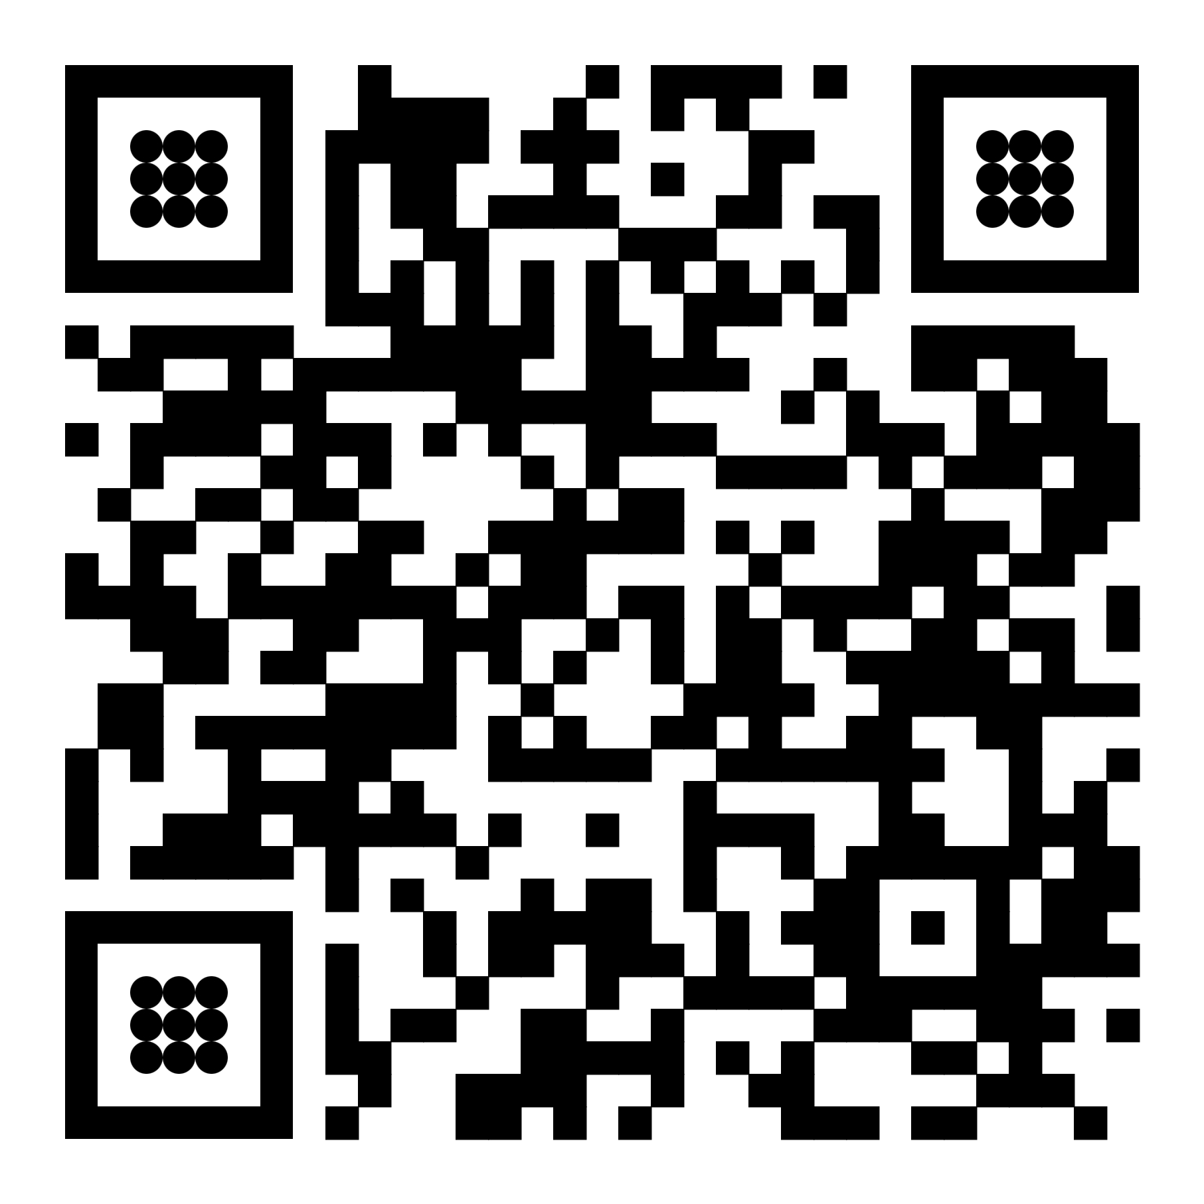
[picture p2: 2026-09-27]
hardware/KiCAD-library/powercoreV3github.png

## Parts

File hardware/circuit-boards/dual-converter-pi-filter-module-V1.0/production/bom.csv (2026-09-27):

Designator | Footprint | Quantity | Value | LCSC Part #
C1, C10, C11, C12, C13, C14, C15, C16, C17, C18, C19, C2, C20, C21, C22, C23, C24, C25, C26, C27, C28, C29, C3, C30, C31, C32, C33, C34, C35, C36, C37, C38, C39, C40, C41, C42, C5, C7, C8, C9 | 1206 | 40 | 10 uF | C96600
C4, C6 | PHA225 | 2 | 560 uF | C3274794
L1 | SRP1245A | 1 | 18uH | C5926042
R1 | 2512 | 1 | 4.7K | C878291

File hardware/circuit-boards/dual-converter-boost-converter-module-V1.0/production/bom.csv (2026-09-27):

Designator | Footprint | Quantity | Value | LCSC Part #
C1, C2, C3, C4, C6, C7, C8, C9 | 1206 | 8 | 10 uF | C96600
C10, C5 | 0603 | 2 | 1 uF | C106215
C11 | 0805 | 1 | 33 uF | C342635
C12 | 0603 | 1 | 39nF | C107091
C14 | 226TTA350M | 1 | 22UF | C6077372
C15, C16 | 2220 | 2 | 2.2 uF | C445674
D1 | D_SMA | 1 | US1M-13-F | C99333
L1 | SRR1210-681M | 1 | 680 uH | NULL
R1, R2, R3 | 0805 | 3 | 200K | C728645
R4, R5 | 0603 | 2 | 2.2K | C3032396
R6 | 0603 | 1 | 49.3K | C861433
R7 | 0603 | 1 | 15K | C855633
R8 | 0603 | 1 | 100K | C844916
R9 | 1206 | 1 | 90mR | C375525
U1 | TPL0401B-10DCKR | 1 | TPL0401B-10DCKR | C2666599
U2 | lm5156h | 1 | LM5156HPWPR | C2867852
U3 | STN3N40K3 | 1 | STN3N40K3 | C128261

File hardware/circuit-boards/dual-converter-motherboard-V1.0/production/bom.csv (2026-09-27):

Designator | Footprint | Quantity | Value | LCSC Part #
C1, C10, C13, C6, C8, C9 | 0603 | 6 | 220 nF | C726565
C11 | 1210 | 1 | 0.1 uF | C141218
C14, C15, C16, C2 | 0603 | 4 | 10000 pF | C115056
C3 | 0805 | 1 | 10 nF | C342860
C7 | 0805 | 1 | 0.47 uF | C596323
D1, D2, D8 | D_SMA | 3 | US1M-13-F | C99333
D10, D6, D7 | D_SMA | 3 | D_Zener | C110525
D3, D4, D5 | STPSC20065GY-TR | 3 | STPSC20065GY-TR | C2965441
D9 | D_SOD-323 | 1 | D_Zener | C82043
J1, J2 | 2601-1102 | 2 | 2601-1102 | C7509568
J10, J12, J13, J14, J4, J5, J6, J7, J8, J9 | PinSocket_2x03_P2.54mm_Vertical | 10 | Conn_02x03_Odd_Even
J11, J15 | PinSocket_1x06_P2.54mm_Vertical | 2 | Conn_01x06_Socket
J16 | PinSocket_1x07_P2.54mm_Vertical | 1 | Conn_01x07_Socket
J3 | S4B-XH-SM4-TB | 1 | S4B-XH-SM4-TB | C161861
L1 | 0402 | 1 | BBUP00100505330Y00 | C668299
Q1 | SUM110P08-11L-E3 | 1 | SUM110P08-11L-E3 | C2838509
Q2 | DMP45H4D9HK3-13 | 1 | DMP45H4D9HK3-13
Q3 | TO-263-2 | 1 | SIHB068N60EF-GE3 | C3009875
R1, R2 | 0603 | 2 | 1K | C22548
R10, R11, R8 | 0805 | 3 | 332K
R12, R14, R17, R20, R21, R25, R3, R4 | 0603 | 8 | 10K | C20161635
R13 | 2512 | 1 | 1R | C840599
R15, R19, R26 | 0603 | 3 | 100R | C20161635
R16, R27 | 2512 | 2 | 1K | C7038808
R18, R28, R29 | 0603 | 3 | 2.2K | C3032396
R22, R23 | 2512 | 2 | 12K | C2082818
R24, R7, R9 | 2512 | 3 | 10R
R5, R6 | 0603 | 2 | 255K | C295887
U4, U6, U7 | UCC23313BDWYR | 3 | UCC23313BDWYR | C2868027
U5 | TMCS1133C3AQDVGR | 1 | TMCS1133C1A | C32266987
U8 | SC0915 | 1 | SC0915 | C7203002

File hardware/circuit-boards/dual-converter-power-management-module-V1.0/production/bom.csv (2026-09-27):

Designator | Footprint | Quantity | Value | LCSC Part #
C1 | 0603 | 1 | 1 uF | C106215
C10, C11, C12, C13, C14, C15, C16, C17, C18, C19, C2, C20, C21, C22, C23, C24, C25, C26, C27, C28, C29, C3, C30, C31, C32, C33, C34, C35, C4, C5, C6, C7, C8, C9 | 1206 | 34 | 10 uF | C96600
D1 | D_SMC | 1 | SMCJ60A-E3/57T | C1975272
L1 | SRP1245A | 1 | 18uH | C5926042
R1, R6, R7 | 0603 | 3 | 100K | C844916
R10, R13 | 2512 | 2 | 1R | C181756
R2, R3, R4, R5 | 0603 | 4 | 2.2K | C114662
R8 | 0603 | 1 | 249R | C861249
R9 | 0603 | 1 | 0R | C95177
U1 | TPS1HTC30-Q1 | 1 | TPS1HTC30AQPWPRQ1 | C22414694

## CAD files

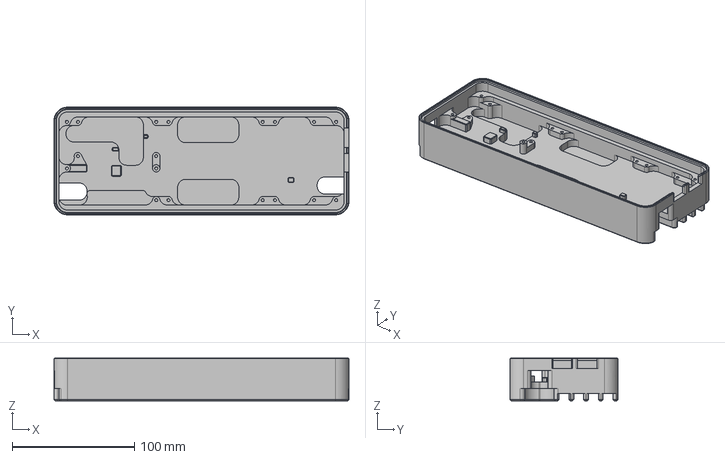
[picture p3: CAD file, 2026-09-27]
hardware/CAD/PCV3-enclosure-revF.step
241.0 x 88.0 x 35.0 mm

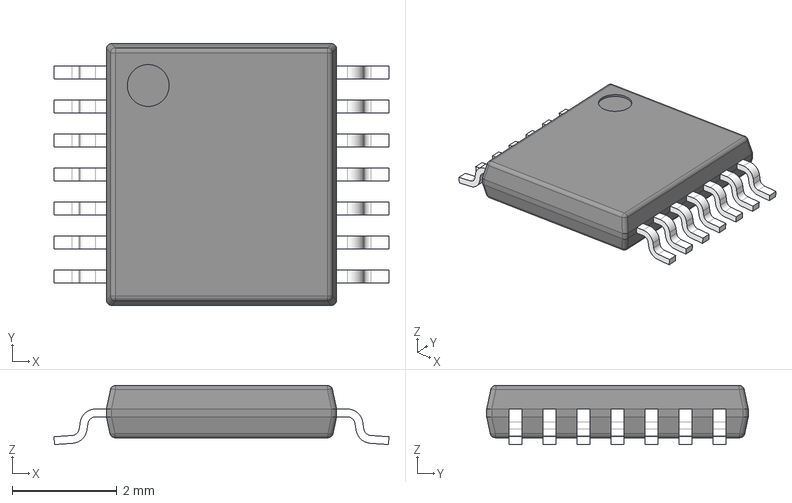
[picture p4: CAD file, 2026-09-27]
hardware/KiCAD-library/3D-models/lm5156h.stp
6.40 x 5.00 x 1.13 mm
BODY-TSSOP
LEAD-TSSOP x 14
PIN1
DAP

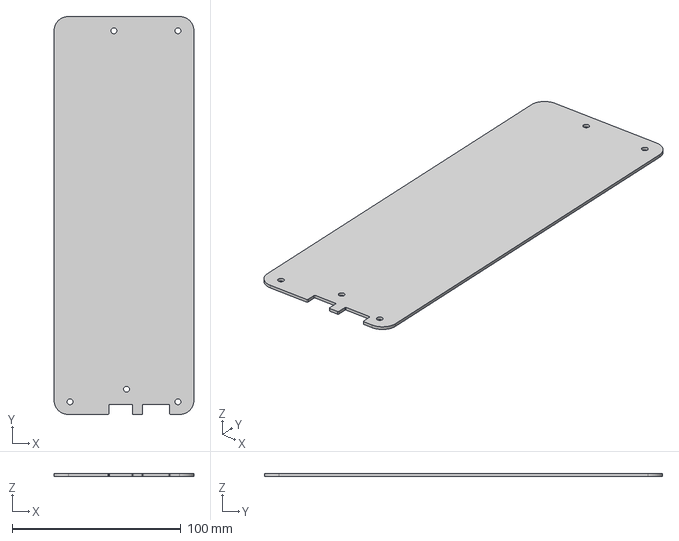
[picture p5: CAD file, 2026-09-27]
hardware/CAD/PCV3-cover-panel-revF.step
83.0 x 236.0 x 1.60 mm

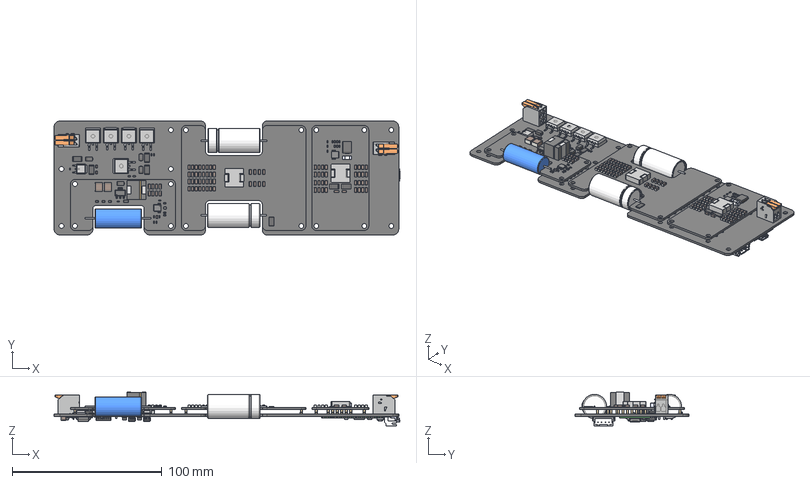
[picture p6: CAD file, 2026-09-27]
hardware/CAD/powercore-V3-revF v2.step
230.8 x 76.0 x 22.3 mm
powercore-V3-revF 1.1.1 x 5
R_2512_6332Metric_2 x 8
D_SMA_1 x 6
C_1206_3216Metric x 34
BODY-SO
LEAD-SO x 14
THERMALPAD-SO
R_0603_1608Metric x 10
SRP1245A series
R_2512_6332Metric x 2
0679H9120-05
D_SMC
dual-converter-power-management-module-V1.0_PCB
R_0603_1608Metric_2 x 18
C_1206_3216Metric_1 x 40
PHA225 x 2
SRP1245A series_1
R_2512_6332Metric_1
dual-converter-pi-filter-module-V1.0_PCB
C_0805_2012Metric_1 x 4
D_SOD-323
C_0603_1608Metric x 4
R_0805_2012Metric x 3
R_1206_3216Metric
R_0603_1608Metric_1 x 5
C_0805_2012Metric
SRR1210-681M
C_1206_3216Metric_2 x 8
BODY-SOT
LEAD-SOT x 6
C_2220_5750Metric x 2
BODY-TSSOP
LEAD-TSSOP x 14
DAP
STN3N40K3
226TTA350M
D_SMA
dual-converter-boost-converter-module-V1.0_PCB
powercore-V3-revF 1.59.1
C_0603_1608Metric_1 x 11
SxB-XH-SM4-TB_4
pin^SxB-XH-SM4-TB Ass x 4
BODY-SSOP x 3
LEAD-SSOP x 18
L_0402_1005Metric
C_1210_3225Metric
SC0915
R_0805_2012Metric_1 x 3
BODY-SOIC
LEAD x 8
LEAD_WIDE x 2
dual-converter-motherboard-V1.0_PCB

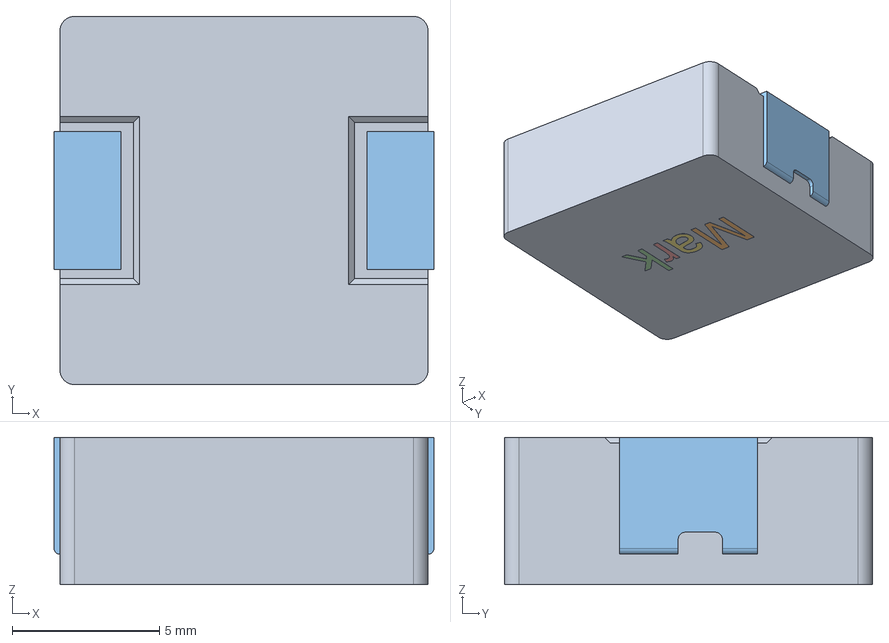
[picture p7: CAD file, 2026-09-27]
hardware/KiCAD-library/3D-models/SRP1245A series.stp
12.9 x 12.5 x 5.00 mm

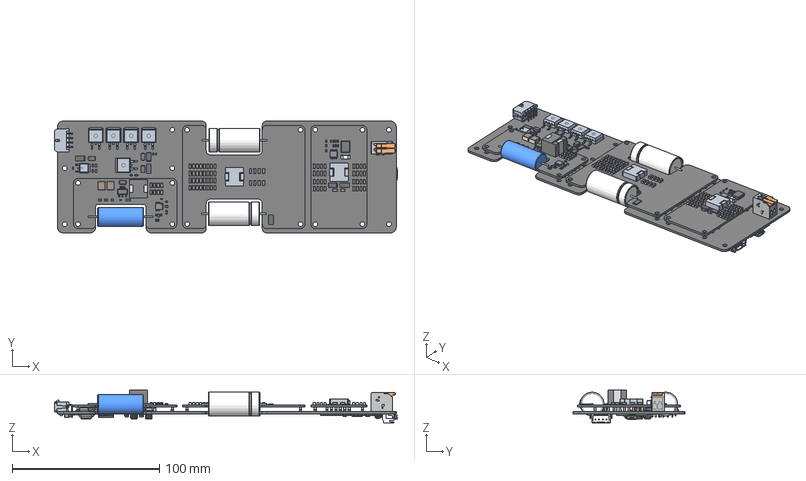
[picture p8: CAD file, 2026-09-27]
hardware/KiCAD-library/3D-models/powercore-V3-revE.step
232.8 x 76.0 x 22.3 mm
powercore-V3-revE 1.1.1 x 5
R_2512_6332Metric x 10
D_SMA x 7
C_1206_3216Metric x 82
BODY-SO
LEAD-SO x 14
THERMALPAD-SO
R_0603_1608Metric x 33
SRP1245A series x 2
0679H9120-05
D_SMC
dual-converter-power-management-module-V1.0_PCB
PHA225 x 2
dual-converter-pi-filter-module-V1.0_PCB
C_0805_2012Metric x 6
D_SOD-323
C_0603_1608Metric x 10
R_0805_2012Metric x 6
R_1206_3216Metric
SRR1210-681M
BODY-SOT
LEAD-SOT x 6
PIN1-ID
C_2220_5750Metric x 2
BODY-TSSOP
LEAD-TSSOP x 14
PIN1 x 4
DAP
STN3N40K3
226TTA350M
dual-converter-boost-converter-module-V1.0_PCB
powercore-V3-revE 1.58.1
SxB-XH-SM4-TB_4
pin^SxB-XH-SM4-TB Ass x 4
BODY-SSOP x 3
LEAD-SSOP x 18
L_0402_1005Metric x 3
C_1210_3225Metric
SC0915
BODY-SOIC
LEAD x 8
LEAD_WIDE x 2
dual-converter-motherboard-V1.0_PCB

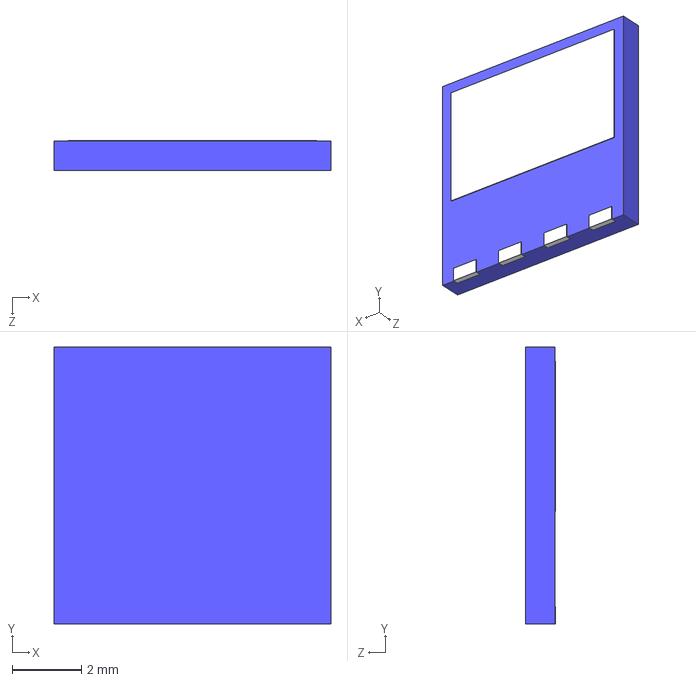
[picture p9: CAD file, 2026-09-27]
hardware/KiCAD-library/3D-models/TK31V60W5,LVQ.step
8.00 x 8.00 x 0.875 mm

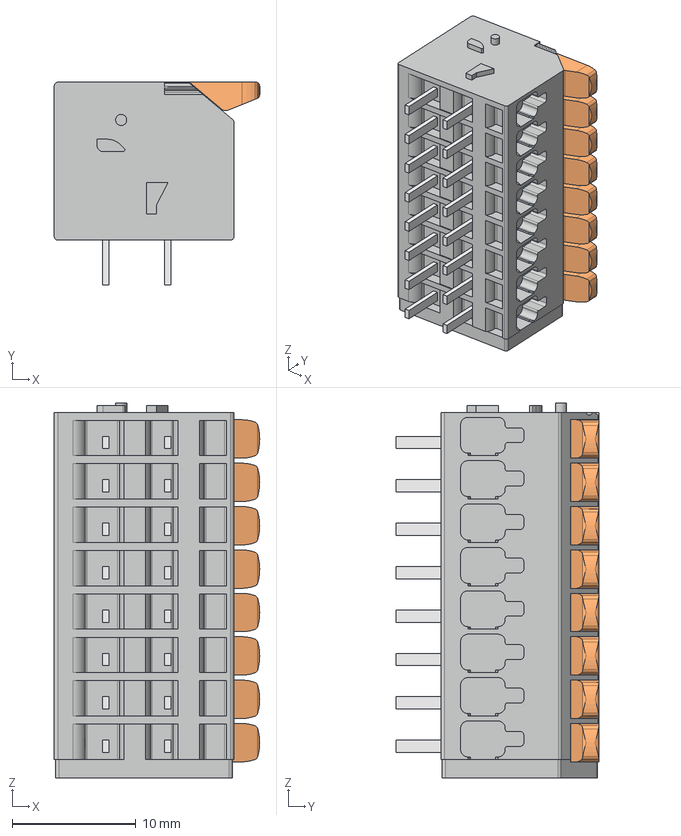
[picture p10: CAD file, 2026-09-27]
hardware/KiCAD-library/3D-models/2601-1108.stp
16.6 x 16.4 x 30.2 mm

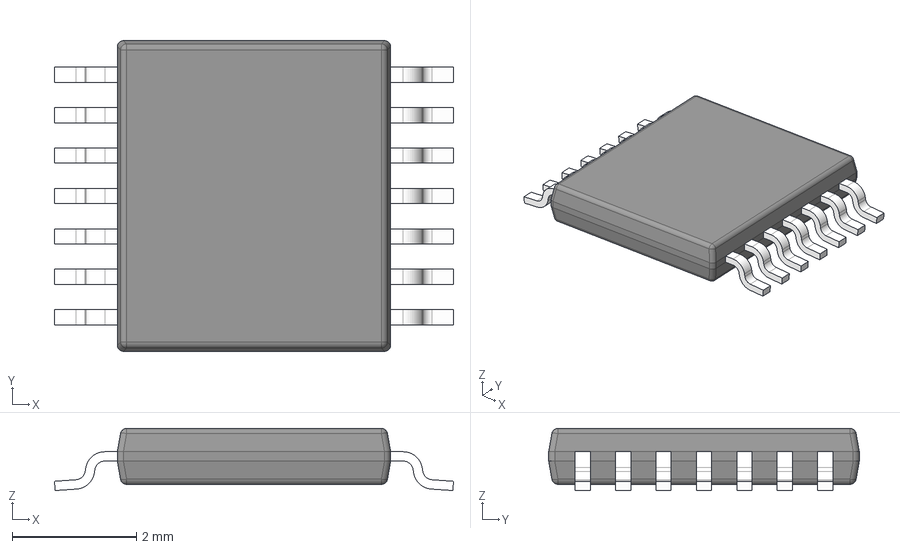
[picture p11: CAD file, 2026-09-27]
hardware/KiCAD-library/3D-models/TPS1HTC30-Q1.stp
6.42 x 5.00 x 1.00 mm
BODY-SO
LEAD-SO x 14
THERMALPAD-SO

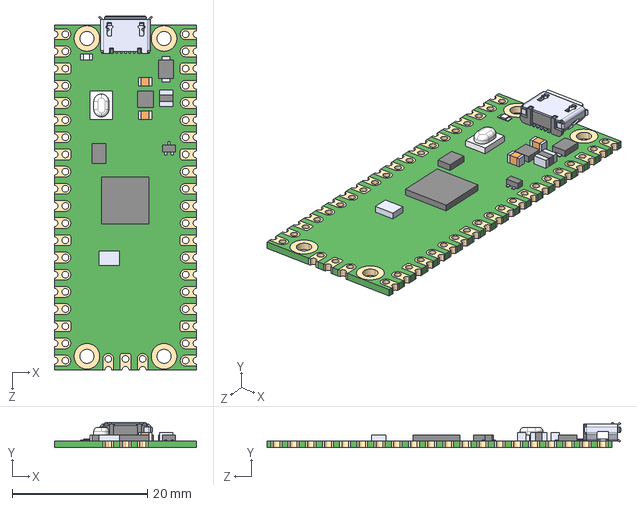
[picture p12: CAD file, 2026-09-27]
hardware/KiCAD-library/3D-models/SC0915.step
21.0 x 3.73 x 52.3 mm

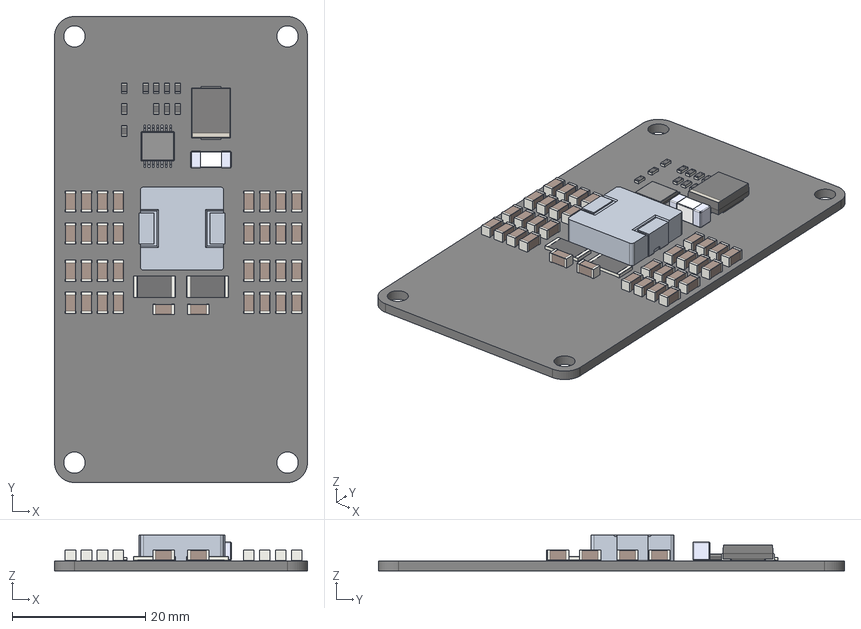
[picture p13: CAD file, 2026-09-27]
hardware/KiCAD-library/3D-models/power-management-module-V1.0.step
38.0 x 70.0 x 5.37 mm
C_1206_3216Metric x 34
BODY-SO
LEAD-SO x 14
THERMALPAD-SO
R_0603_1608Metric x 10
SRP1245A series
R_2512_6332Metric x 2
0679H9120-05
D_SMC
dual-converter-power-management-module-V1.0_PCB

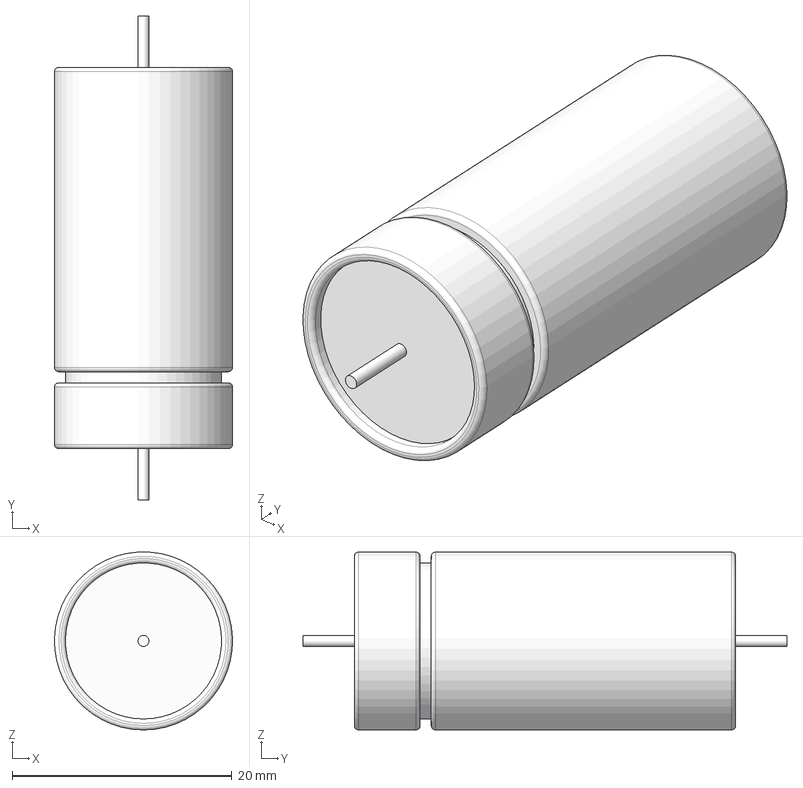
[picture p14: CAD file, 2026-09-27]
hardware/KiCAD-library/3D-models/PHA225.step
16.2 x 44.0 x 16.2 mm

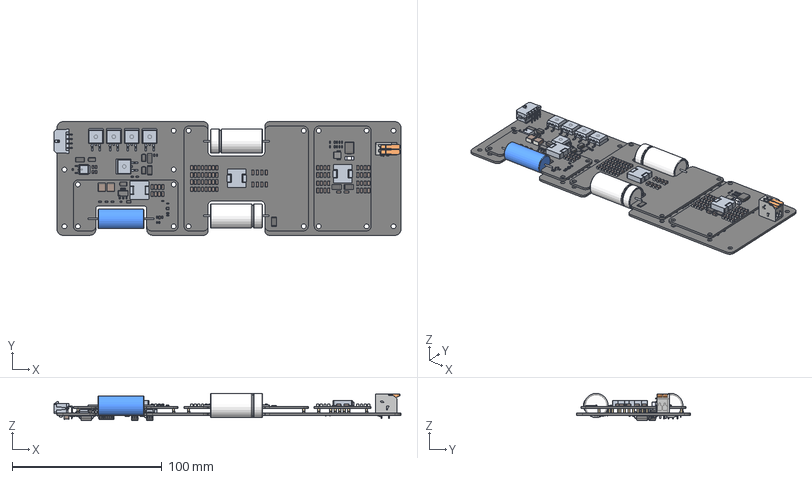
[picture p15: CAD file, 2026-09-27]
hardware/KiCAD-library/3D-models/powercore-V3-revD.step
232.0 x 76.0 x 18.2 mm
powercore-V3-revD 1.1.1 x 5
R_2512_6332Metric x 10
D_SMA x 4
R_0603_1608Metric x 33
C_1206_3216Metric x 82
BODY-SO
LEAD-SO x 14
THERMALPAD-SO
SRP1245A series x 3
0679H9120-05
D_SMC
dual-converter-power-management-module-V1.0_PCB
PHA225 x 2
dual-converter-pi-filter-module-V1.0_PCB
C_0805_2012Metric x 6
D_SOD-323 x 4
C_0603_1608Metric x 10
R_0805_2012Metric x 6
R_1206_3216Metric
BODY-SOT
LEAD-SOT x 6
PIN1-ID
C_2220_5750Metric x 2
STN3N40K3
226TTA350M
dual-converter-boost-converter-module-V1.0_PCB
powercore-V3-revD 1.57.1
BODY-SSOP x 3
LEAD-SSOP x 18
PIN1 x 3
L_0402_1005Metric x 3
C_1210_3225Metric
BODY-SOIC
LEAD x 8
LEAD_WIDE x 2
dual-converter-motherboard-V1.0_PCB

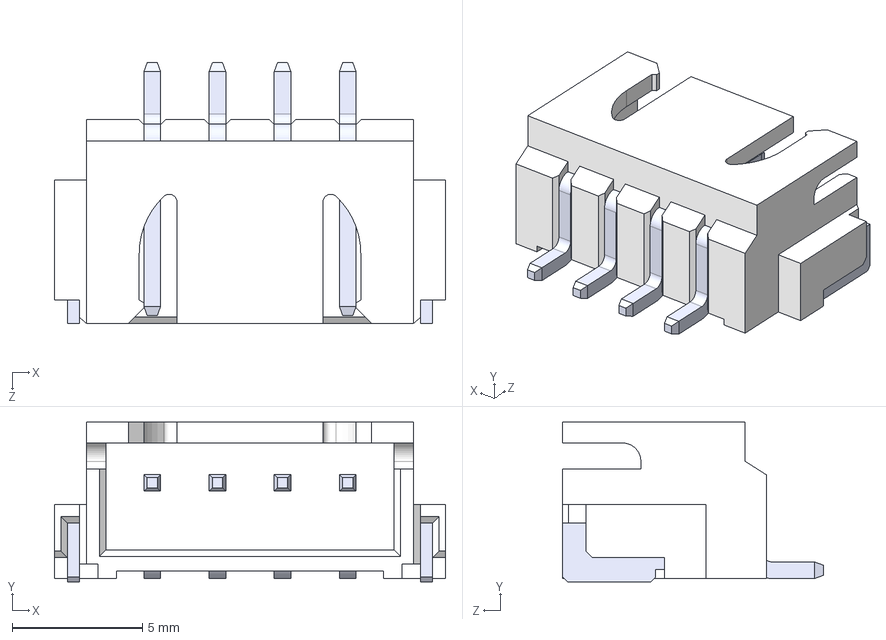
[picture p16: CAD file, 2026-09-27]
hardware/KiCAD-library/3D-models/S4B-XH-SM4-TB.STEP
15.0 x 6.12 x 10.0 mm
SxB-XH-SM4-TB_4
pin^SxB-XH-SM4-TB Ass x 4

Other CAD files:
hardware/KiCAD-library/3D-models/BSZ070N08LS5ATMA1.step
hardware/KiCAD-library/3D-models/SRR1210-681M.step
hardware/KiCAD-library/3D-models/2601-1102.stp
hardware/KiCAD-library/3D-models/226TTA350M.step
hardware/KiCAD-library/3D-models/0679H9120-05.step
hardware/KiCAD-library/3D-models/0906-8-15-20-76-14-11-0.step
hardware/KiCAD-library/3D-models/430450409.step
hardware/KiCAD-library/3D-models/430450822.step
hardware/KiCAD-library/3D-models/BSZ146N10LS5ATMA1.step
hardware/KiCAD-library/3D-models/IAUC70N08S5N074ATMA1.step
hardware/KiCAD-library/3D-models/IHLP6767GZER2R2M51.step
hardware/KiCAD-library/3D-models/LM5149-Q1.stp
hardware/KiCAD-library/3D-models/S3B-PH-SM4-TB.step
hardware/KiCAD-library/3D-models/STN3N40K3.step
hardware/KiCAD-library/3D-models/TMCS1108A3UQDRQ1.stp
hardware/KiCAD-library/3D-models/TMCS1133C3AQDVGR.stp
hardware/KiCAD-library/3D-models/TPL0401B-10DCKR.stp
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

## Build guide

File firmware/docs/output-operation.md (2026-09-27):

# Powercore V3 — Output Stage Operation

## Output Switches

Three MOSFETs form the output stage, all driven by hardware PWM from the RP2040:

| Pin | Signal | Type | Logic | Function |
|-----|---|---|---|---|
| GP8 | `SW_HIGH_VOLTAGE_PHASE` | P-channel | Inverted (HIGH=OFF, LOW=ON) | Connects boost converter (64–100 V) to (+) output to pre-charge output capacitor to spark initiation voltage |
| GP10 | `SW_ENABLE` | N-channel | Normal (HIGH=ON, LOW=OFF) | Connects (–) electrode to GND through output current sensor (TMCS1133) |
| GP11 | `SW_HIGH_CURRENT_PHASE` | P-channel | Inverted (HIGH=OFF, LOW=ON) | Connects 48 V high-current phase (pi-filter output) to (+) output to drive machining current |

In the safe/disabled state: `SW_ENABLE` is driven LOW, both P-channel gates are driven HIGH via GPIO (overriding PWM).

---

## Timing — Hardware PWM, No Interrupts

All switch timing is handled entirely by the RP2040 PWM hardware. There are no ISRs, delays, or software loops involved in the switching cadence. Once `pwm_set_enabled()` is called, the hardware runs autonomously.

**Phase-correct (center-aligned) mode** is used on all slices. The counter counts up to `wrap`, then back down to 0. The output is HIGH when `counter ≤ level` on both the up- and down-count, producing a symmetric pulse centered at counter = 0.

```
pwmWrapValue  = 133,000,000 / (frequency_Hz × 2)
pwmLevelValue = pwmWrapValue × dutyCycle
```

At 10 kHz, 10% duty cycle: `wrap = 6,650`, `level = 665`, period = 100 μs, on-time = 10 μs.

---

## Two PWM Slices

The three switches are split across two slices, both configured identically and enabled simultaneously:

| Slice | Pins | Switches | Level |
|---|---|---|---|
| Slice 5 | GP10, GP11 | `SW_ENABLE` + `SW_HIGH_CURRENT_PHASE` | `pwmLevelValue` (machining duty cycle) |
| Slice 4 | GP8, GP9 | `SW_HIGH_VOLTAGE_PHASE` + `OUTPUT_OVERCURRENT_SET` | `pwmHighVoltageLevelValue` (fixed 1 μs) |

P-channel polarity inversion is handled in hardware via `pwm_set_output_polarity()`, so both switches on Slice 5 turn on and off together with no additional logic.

---

## Switching Sequence Per EDM Cycle

The HV slice counter is pre-loaded to 25% of `wrap` before being enabled:

```
pwm_set_counter(slice4, wrap × 0.25)  // = 1,662 counts at 10 kHz
```

Both slices then run at identical rates, so this offset is fixed. The result at 10 kHz:

```
t = 0–10 μs    Machining pulse — SW_ENABLE + SW_HIGH_CURRENT_PHASE ON
               48 V applied across gap; 40–70 A flows through discharge
t = 10–87 μs   All switches OFF — gap de-ionizes, dielectric recovers
t = 87–88 μs   HV pre-charge pulse — SW_HIGH_VOLTAGE_PHASE ON (~1 μs)
               Boost converter charges output capacitor to spark initiation voltage (64–100 V)
t = 88–100 μs  All switches OFF — ~7 μs settling before next machining pulse
```

The 7 μs gap between the HV pulse and the machining pulse prevents shoot-through (both phases conducting simultaneously). The 1 μs HV pulse duration and 25% offset are fixed constants in the firmware (`EDMIsofrequencyModeHighVoltagePulseOnTimeMicros = 1`, `EDMIsofrequencyModeHighVoltagePwmOffsetValue = 0.25`).

---

## Discharge Detection

The TMCS1133 output current sensor has a hardware comparator output (`OUTPUT_OVERCURRENT`, GP12) that asserts on a falling edge when machining current exceeds the threshold (default 8 A). This fires an ISR that:

1. Snapshots the output current and voltage ADC readings
2. Increments the discharge counters
3. Sets the `newDischargeDetected` flag for the main loop

The ISR does **not** modify switch state. The main loop processes the flag on its next iteration.

The overcurrent threshold level is set via PWM on `OUTPUT_OVERCURRENT_SET` (GP9, same slice as `SW_HIGH_VOLTAGE_PHASE`), calculated as:

```
threshold_voltage = (0.025 V/A × threshold_A) / 2.5
threshold_level   = (threshold_voltage / 3.3) × wrap
```

---

## Pulse Skipping

The main loop (`EDMIsofrequencyMode()`) monitors two conditions and suppresses output by calling `disableOutputStage()` when either is exceeded:

| Condition | Threshold | Pause Duration |
|---|---|---|
| Discharge success rate | > 80% over calculation window | 250 ms |
| Average input power | > 75 W | 10 ms |

After a pause, `setupOutputPWMForEDMIsofrequencyMode()` re-enables the PWM. Power consumption is reported to the external motion controller via the `EDM_FEEDBACK` PWM pin (GP3, 1 kHz, active-low: 0% = at power limit, 100% = no load).

---

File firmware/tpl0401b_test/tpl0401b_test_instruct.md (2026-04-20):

// GENERATED BY CLAUDE CODE - VIBED BY DANIELKM-EE

● Created at firmware/tpl0401b_test/tpl0401b_test.ino. Here's what it does and
  why I made each choice:

  Pin / address config matches firmware.ino exactly — SDA=16, SCL=17, addr 0x3E,
   10kHz — so it's a drop-in test on the same hardware without rewiring.

  Wire library instead of raw SDK — cleaner for a test sketch, and the Earle
  Philhower core supports Wire.setSDA()/Wire.setSCL() for custom pins.

  Four test commands over serial (115200 baud):

  ┌─────────┬────────────────────────────────────────────────────────────────┐
  │ Command │                         What it checks                         │
  ├─────────┼────────────────────────────────────────────────────────────────┤
  │         │ Confirms the device is present at 0x3E and reports any other   │
  │ SCAN    │ devices on the bus (useful for diagnosing address conflicts or │
  │         │  pull-up issues)                                               │
  ├─────────┼────────────────────────────────────────────────────────────────┤
  │ READ    │ Reads the current wiper register and prints it                 │
  ├─────────┼────────────────────────────────────────────────────────────────┤
  │ SET <n> │ Writes position n (0–127) then immediately reads back and      │
  │         │ checks for a match — isolates write-vs-read failures           │
  ├─────────┼────────────────────────────────────────────────────────────────┤
  │         │ Steps 0→127→0 with per-step readback verification, printing OK │
  │ SWEEP   │  or MISMATCH at each position — good for catching intermittent │
  │         │  I2C glitches                                                  │
  └─────────┴────────────────────────────────────────────────────────────────┘

  A note on position range: the main firmware clamps to 0–110 for safe HV
  operation, but the TPL0401B is a 128-position (0–127) part, so this test
  exposes the full range. Your hardware team should avoid connecting the boost
  converter output while sweeping past 110.

✻ Churned for 1m 4s

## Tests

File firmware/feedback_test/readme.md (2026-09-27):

# feedback_test

Standalone sweep test for the `EDM_FEEDBACK` PWM output. Continuously
sweeps GP3 between 200 Hz and 400 Hz (50% duty cycle) so the signal can
be verified with an oscilloscope or frequency counter. Progress is printed
over USB CDC at 115200 baud.

## Prerequisites

- Pico SDK at `~/.local/share/pico-sdk` (or set `PICO_SDK_PATH` in your
  environment)
- CMake ≥ 3.13 and the `arm-none-eabi-gcc` toolchain
- picotool at `~/.local/share/picotool-src/build/picotool`

Add picotool to your path for convenience:

```bash
export PATH="$HOME/.local/share/picotool-src/build:$PATH"
```

## Build

```bash
cd firmware/feedback_test
mkdir -p build && cd build
PICO_SDK_PATH=~/.local/share/pico-sdk cmake ..
make -j$(nproc)
```

The build produces `feedback_test.uf2` in the `build/` directory.

## Flash

Put the Pico into BOOTSEL mode (hold BOOTSEL while plugging in USB, or
press BOOTSEL + RUN then release RUN), then:

```bash
picotool load -x build/feedback_test.uf2
```

`-x` reboots the device automatically after flashing. If the device is
already running firmware that supports `picotool reboot`, you can skip
the manual BOOTSEL step:

```bash
picotool reboot -f -u   # force reboot into BOOTSEL
picotool load -x build/feedback_test.uf2
```

## Monitor serial output

```bash
minicom -b 115200 -D /dev/ttyACM0
```

Expected output:

```
EDM_FEEDBACK sweep test: GP3, 200 Hz <-> 400 Hz
ratio=0.00  freq=200 Hz
ratio=0.01  freq=202 Hz
...
ratio=1.00  freq=400 Hz
ratio=0.99  freq=398 Hz
...
```

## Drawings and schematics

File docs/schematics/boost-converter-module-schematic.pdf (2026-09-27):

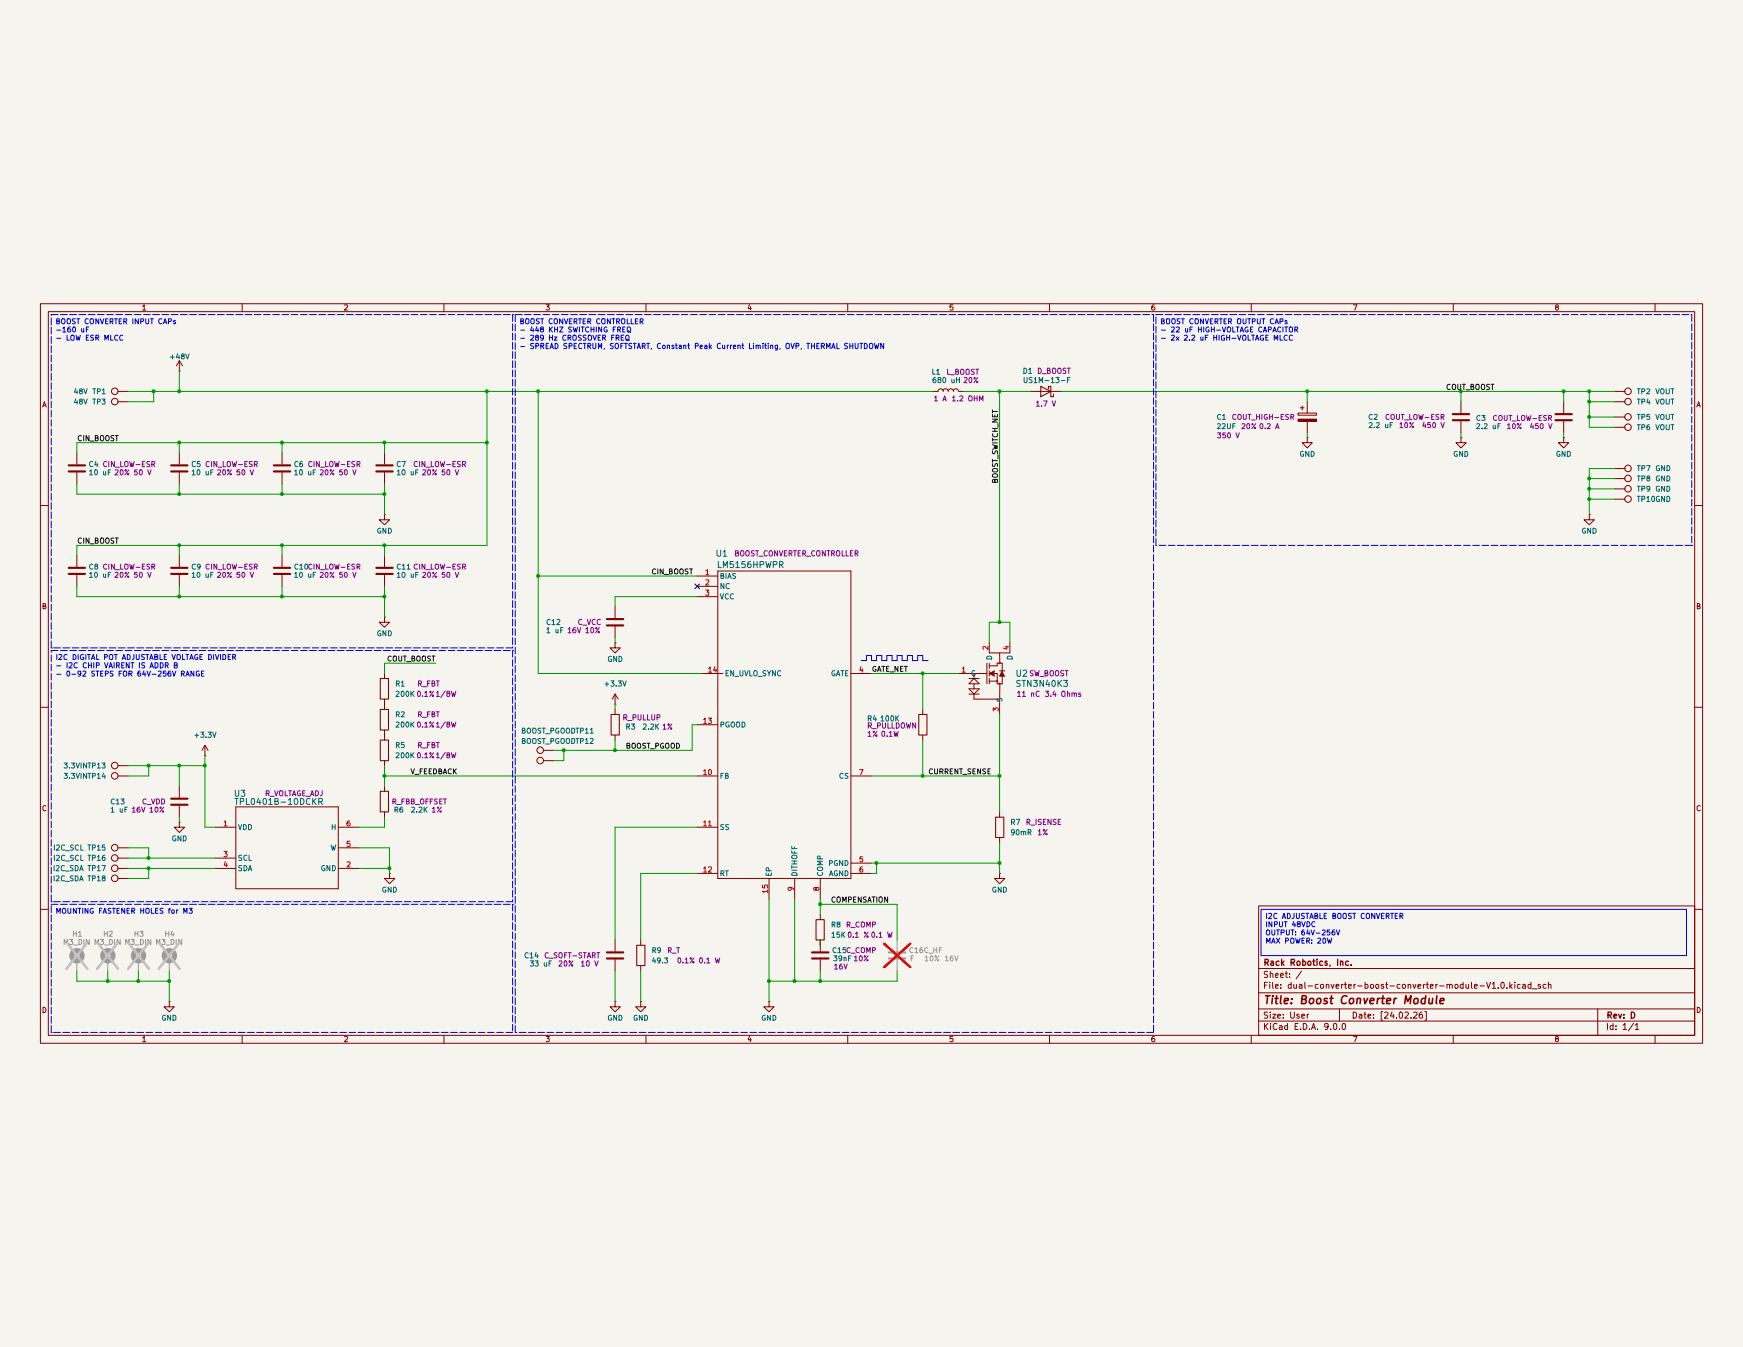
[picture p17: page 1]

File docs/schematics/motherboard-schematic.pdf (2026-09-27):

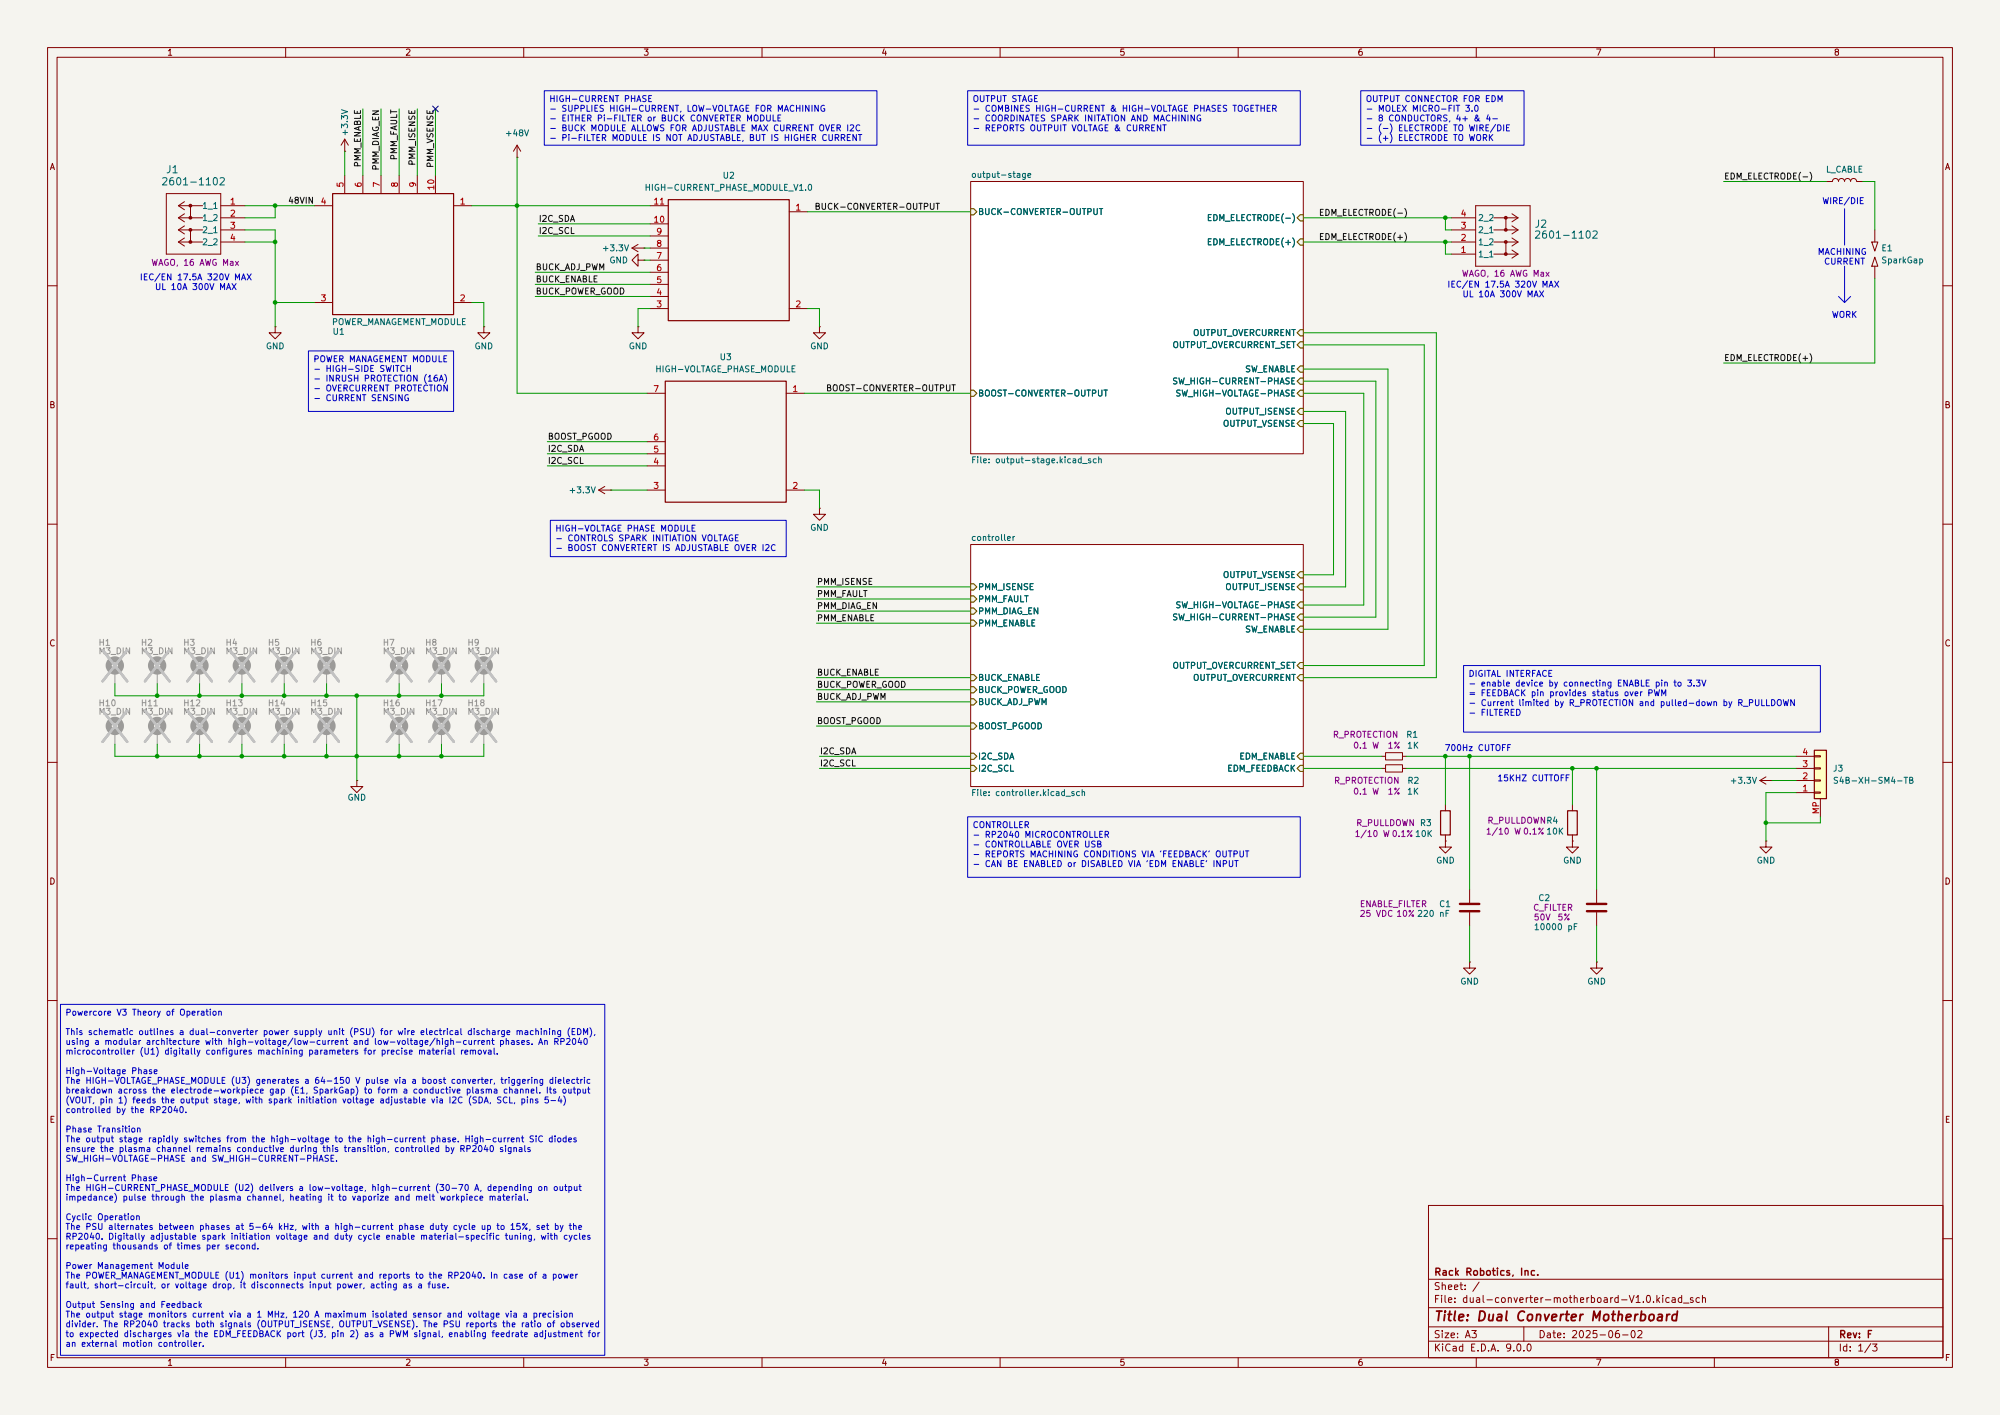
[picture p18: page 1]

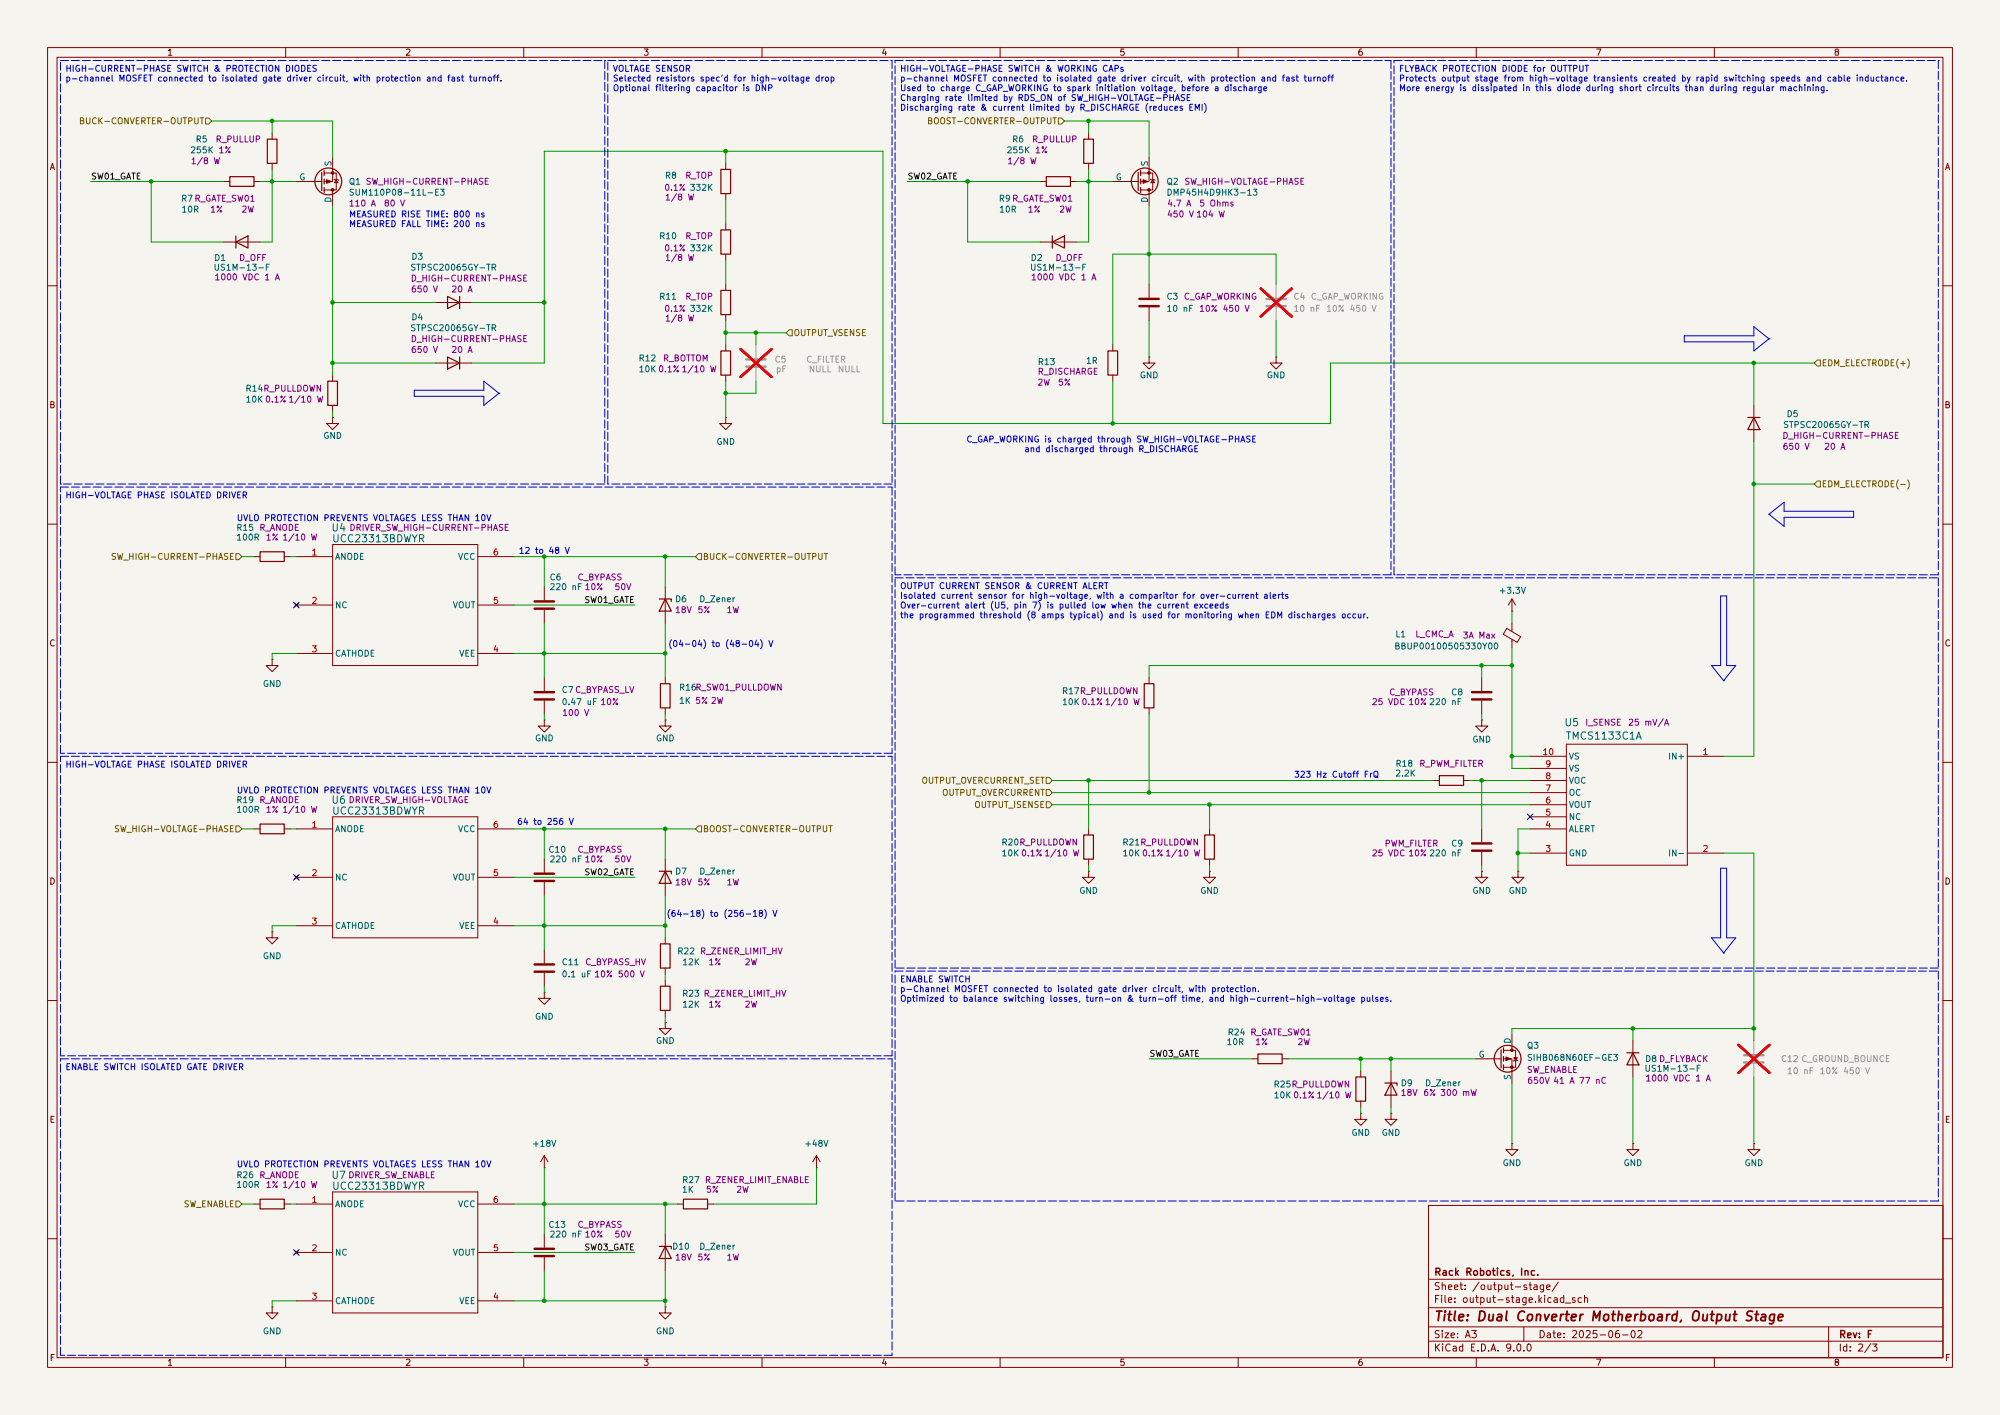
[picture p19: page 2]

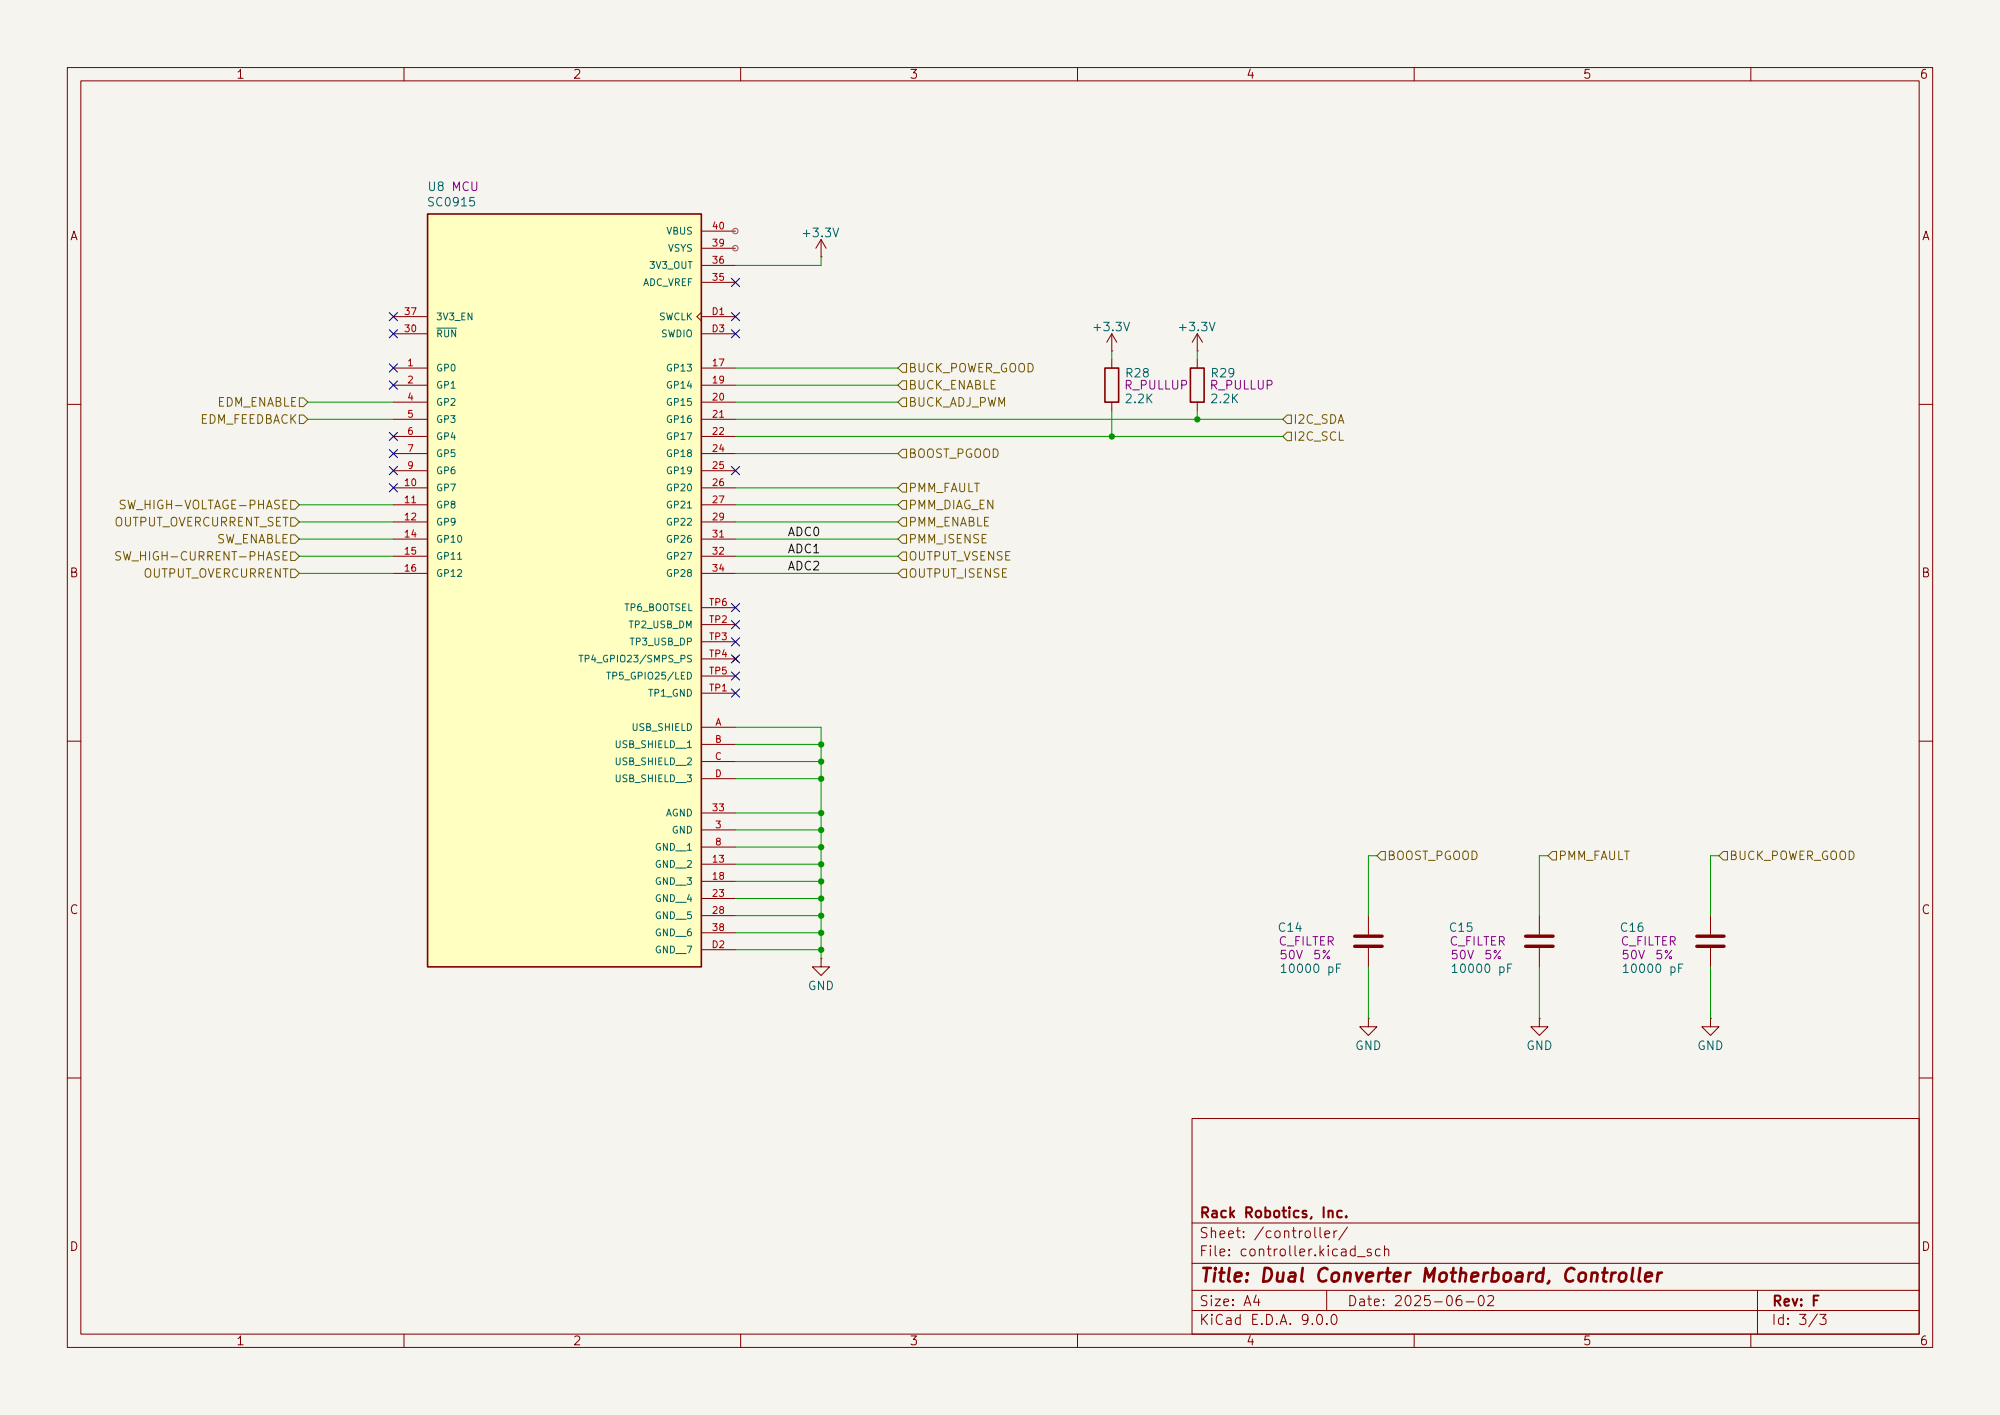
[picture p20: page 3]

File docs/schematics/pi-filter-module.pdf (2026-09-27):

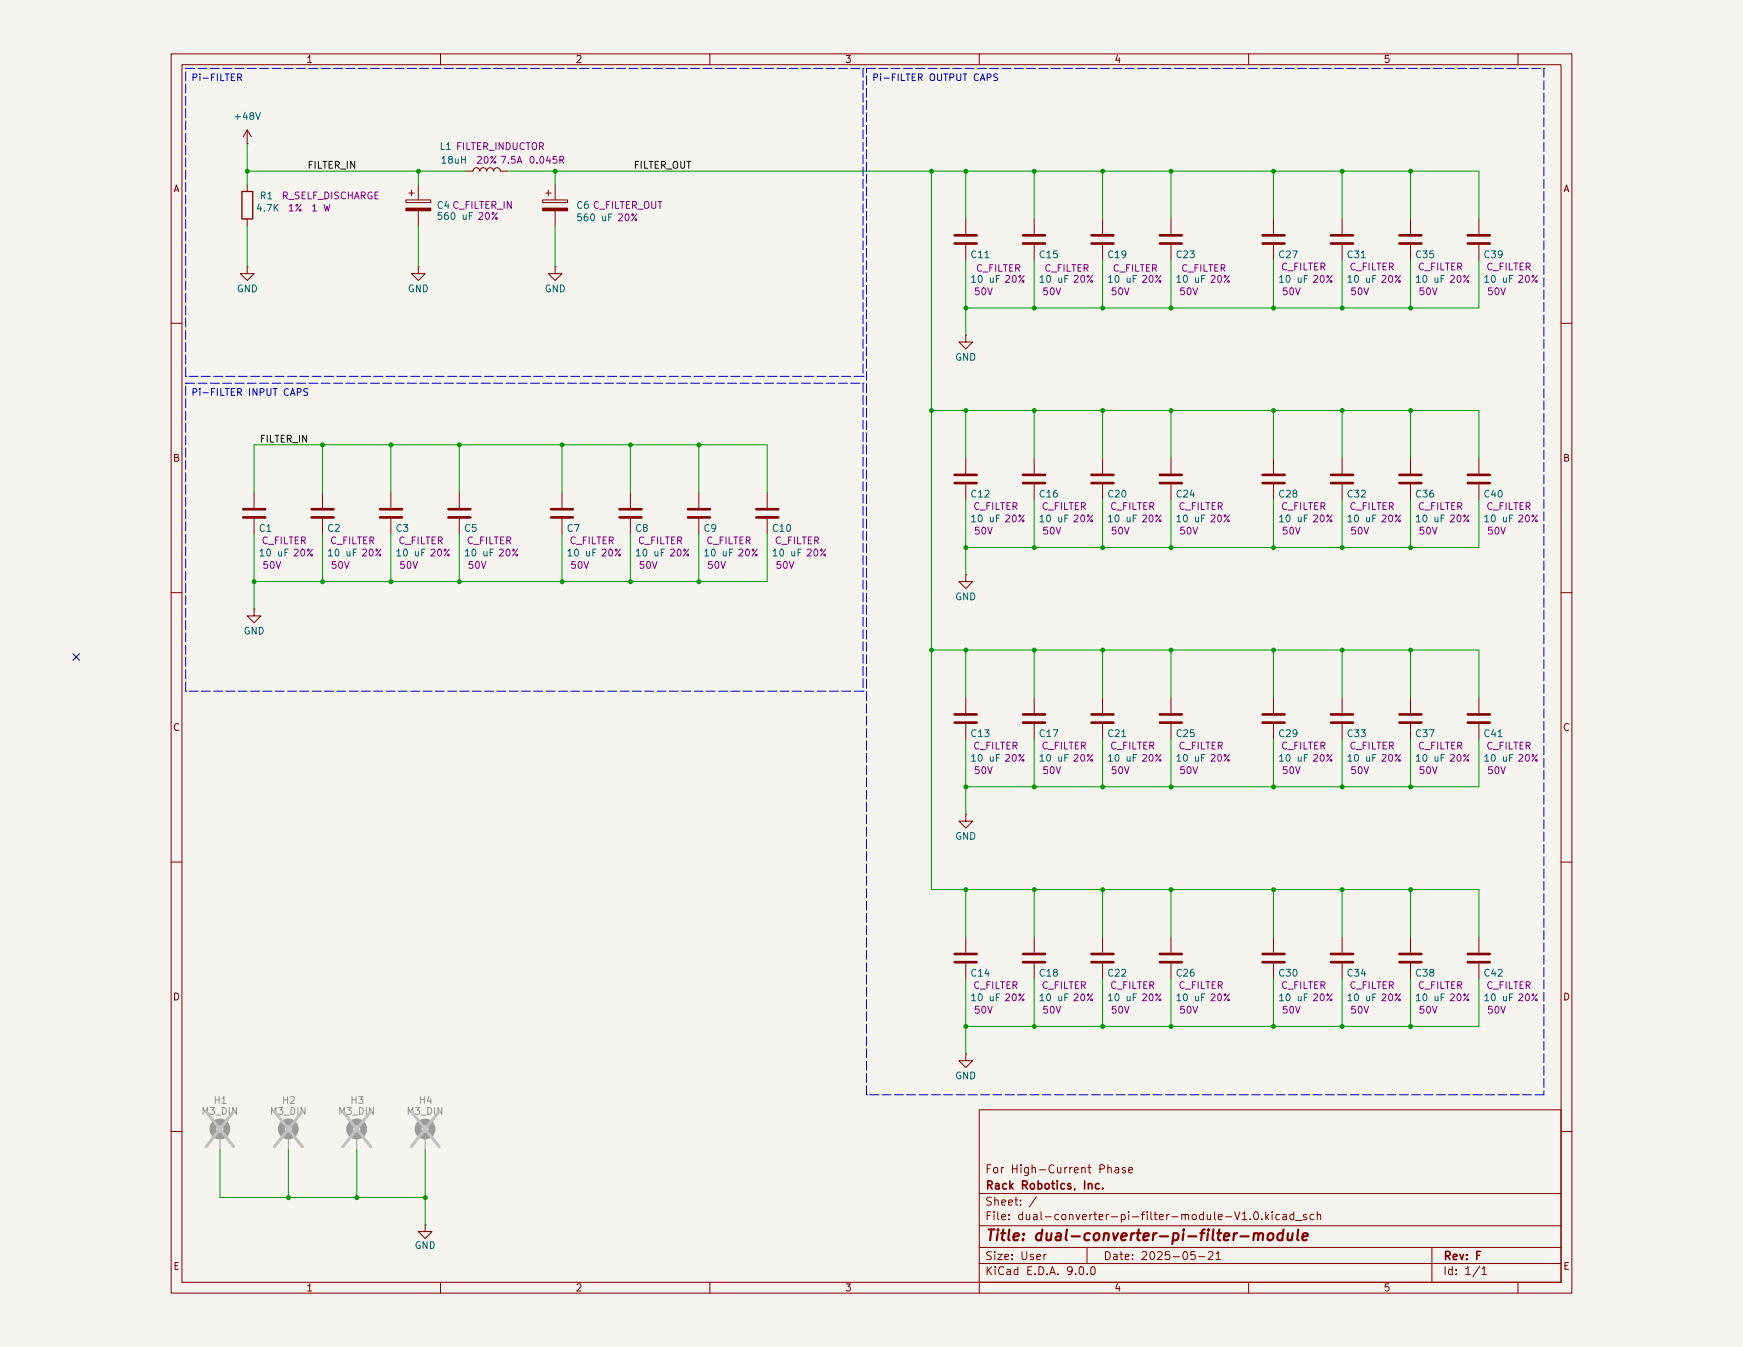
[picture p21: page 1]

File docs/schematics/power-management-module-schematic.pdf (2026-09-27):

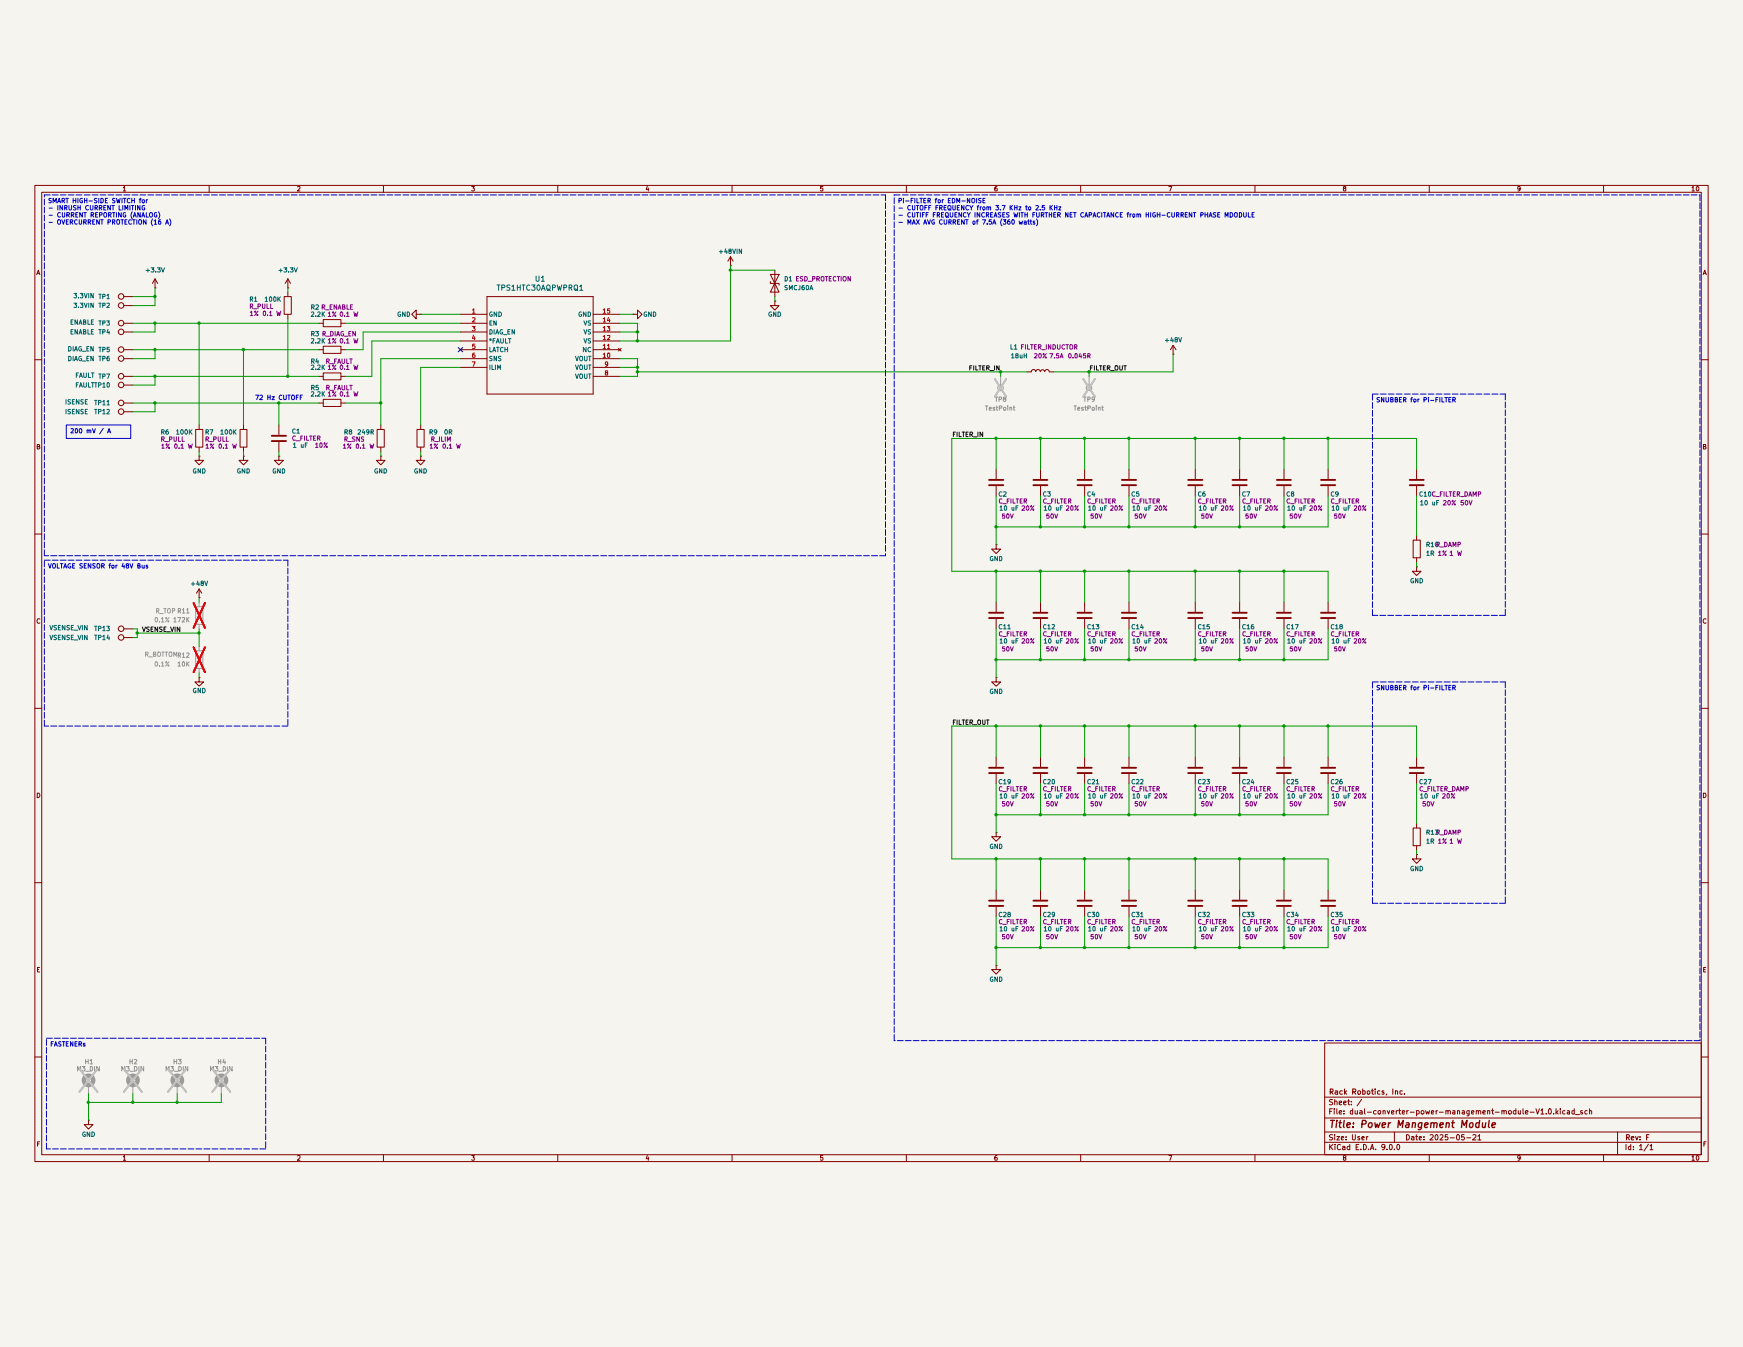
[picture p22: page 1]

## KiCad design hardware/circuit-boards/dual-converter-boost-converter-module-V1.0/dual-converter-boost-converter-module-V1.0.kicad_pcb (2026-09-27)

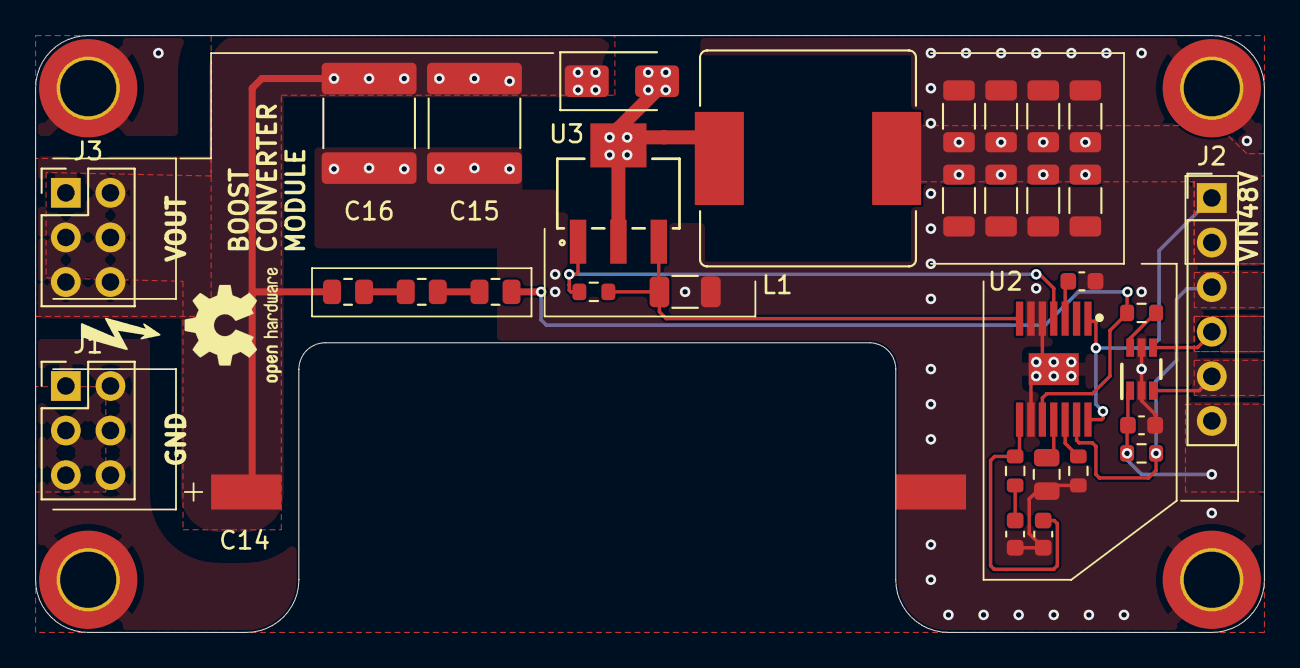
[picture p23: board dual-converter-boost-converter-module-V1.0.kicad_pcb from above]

Board: 4 copper layers, 70.0 x 34.0 mm, 37 parts (0 on the bottom side), 19 nets.

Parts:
C1, C2, C3, C4, C6, C7, C8, C9: 10 uF; C_1206_3216Metric
C5, C10: 1 uF; C_0603_1608Metric
C11: 33 uF; C_0805_2012Metric
C12: 39nF; C_0603_1608Metric
C13: F; C_0603_1608Metric
C14: 22UF; 226TTA350M
C15, C16: 2.2 uF; C_2220_5750Metric
D1: US1M-13-F; D_SMA
H1, H2, H3, H4: M3_DIN; MountingHole_3.2mm_M3_DIN965_Pad_TopBottom
J1, J3: Vout Conn; PinHeader_2x03_P2.54mm_Vertical
J2: Conn_01x06; PinHeader_1x06_P2.54mm_Vertical
L1: 680 uH; SRR1210-681M
R1, R2, R3: 200K; R_0805_2012Metric
R4, R5: 2.2K; R_0603_1608Metric
R6: 49.3K; R_0603_1608Metric
R7: 15K; R_0603_1608Metric
R8: 100K; R_0603_1608Metric
R9: 90mR; R_1206_3216Metric
U1: TPL0401B-10DCKR
U2: LM5156HPWPR; lm5156h
U3: STN3N40K3

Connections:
+3.3V: C5.1, J2.6, R5.1, U1.1 (VDD)
+48V: C1.1, C2.1, C3.1, C4.1, C6.1, C7.1, C8.1, C9.1, J2.1, J2.2, L1.1, U2.1 (BIAS), U2.14 (EN_UVLO_SYNC)
/BOOST_PGOOD: J2.3, R5.2, U2.13 (PGOOD)
/BOOST_SWITCH_NET: D1.2 (A), L1.2, U3.2 (D), U3.4 (D)
/COMPENSATION: C13.1, R7.1, U2.8 (COMP)
/COUT_BOOST: C14.1, C15.1, C16.1, D1.1 (K), J3.1, J3.2, J3.3, J3.4, J3.5, J3.6, R1.1
/CURRENT_SENSE: R8.2, R9.1, U2.7 (CS), U3.3 (S)
/GATE_NET: R8.1, U2.4 (GATE), U3.1 (G)
/V_FEEDBACK: R3.2, R4.2, U2.10 (FB)
GND: C1.2, C2.2, C3.2, C4.2, C5.2, C6.2, C7.2, C8.2, C9.2, C10.2, C11.2, C12.2, C13.2, C14.2, C15.2, C16.2, H1.1, H2.1, H3.1, H4.1, J1.1, J1.2, J1.3, J1.4, J1.5, J1.6, R6.2, R9.2, U1.2 (GND), U1.5 (W), U2.5 (PGND), U2.6 (AGND), U2.9 (DITHOFF), U2.15 (EP)
unnamed: C12.1, R7.2
unnamed: J2.4, U1.4 (SDA)
unnamed: J2.5, U1.3 (SCL)
unnamed: R1.2, R2.1
unnamed: R2.2, R3.1
unnamed: R4.1, U1.6 (H)
unnamed: R6.1, U2.12 (RT)
unnamed: C11.1, U2.11 (SS)
unnamed: C10.1, U2.3 (VCC)

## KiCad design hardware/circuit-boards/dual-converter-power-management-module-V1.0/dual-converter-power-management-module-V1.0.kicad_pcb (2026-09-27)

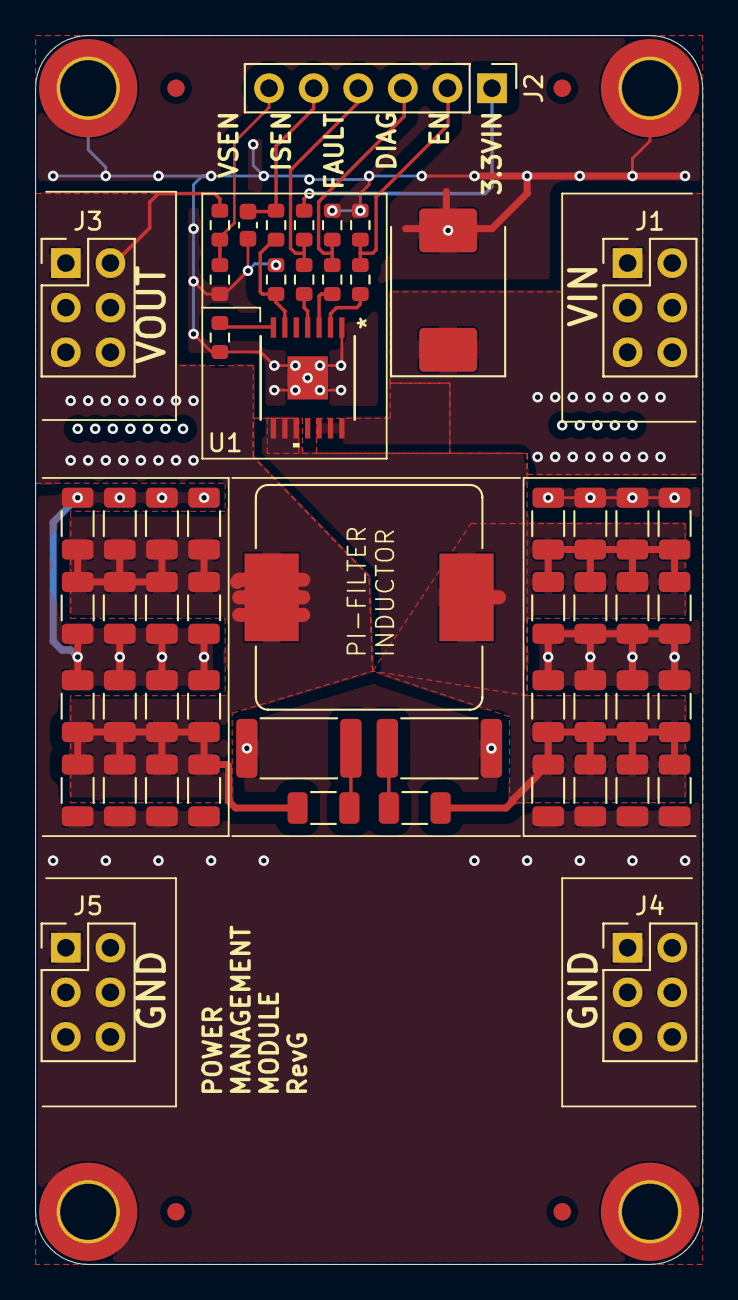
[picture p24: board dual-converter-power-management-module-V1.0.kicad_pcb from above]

Board: 4 copper layers, 38.0 x 70.0 mm, 60 parts (0 on the bottom side), 17 nets.

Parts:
C1: 1 uF; C_0603_1608Metric
C2, C3, C4, C5, C6, C7, C8, C9, C10, C11, C12, C13, C14, C15, C16, C17, C18, C19, C20, C21, C22, C23, C24, C25, C26, C27, C28, C29, C30, C31, C32, C33, C34, C35: 10 uF; C_1206_3216Metric
D1: SMCJ60A-E3/57T; D_SMC
H1, H2, H3, H4: M3_DIN; MountingHole_3.2mm_M3_DIN965_Pad_TopBottom
J1, J3, J4, J5: Conn_02x03_Odd_Even; PinHeader_2x03_P2.54mm_Vertical
J2: Conn_01x06_Pin; PinHeader_1x06_P2.54mm_Vertical
L1: 18uH; SRP1245A
R1, R6, R7: 100K; R_0603_1608Metric
R2, R3, R4, R5: 2.2K; R_0603_1608Metric
R8: 249R; R_0603_1608Metric
R9: 0R; R_0603_1608Metric
R10, R13: 1R; R_2512_6332Metric
R11: 172K; R_0603_1608Metric
R12: 10K; R_0603_1608Metric
U1: TPS1HTC30AQPWPRQ1; TPS1HTC30-Q1

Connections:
+3.3V: J2.1, R1.1
+48V: C19.1, C20.1, C21.1, C22.1, C23.1, C24.1, C25.1, C26.1, C27.1, C28.1, C29.1, C30.1, C31.1, C32.1, C33.1, C34.1, C35.1, J3.1, J3.2, J3.3, J3.4, J3.5, J3.6, L1.2, R11.1
+48VIN: D1.1 (A1), J1.1, J1.2, J1.3, J1.4, J1.5, J1.6, U1.12 (VS), U1.13 (VS), U1.14 (VS)
/FILTER_IN: C2.1, C3.1, C4.1, C5.1, C6.1, C7.1, C8.1, C9.1, C10.1, C11.1, C12.1, C13.1, C14.1, C15.1, C16.1, C17.1, C18.1, L1.1, U1.8 (VOUT), U1.9 (VOUT), U1.10 (VOUT)
GND: C1.2, C2.2, C3.2, C4.2, C5.2, C6.2, C7.2, C8.2, C9.2, C11.2, C12.2, C13.2, C14.2, C15.2, C16.2, C17.2, C18.2, C19.2, C20.2, C21.2, C22.2, C23.2, C24.2, C25.2, C26.2, C28.2, C29.2, C30.2, C31.2, C32.2, C33.2, C34.2, C35.2, D1.2 (A2), H1.1, H2.1, H3.1, H4.1, J4.1, J4.2, J4.3, J4.4, J4.5, J4.6, J5.1, J5.2, J5.3, J5.4, J5.5, J5.6, R6.2, R7.2, R8.2, R9.2, R10.2, R12.2, R13.2, U1.1 (GND)
unnamed: C10.2, R10.1
unnamed: C27.2, R13.1
unnamed: J2.2, R2.1, R6.1
unnamed: J2.3, R3.1, R7.1
unnamed: J2.4, R1.2, R4.1
unnamed: C1.1, J2.5, R5.1
unnamed: R4.2, U1.4 (*FAULT)
unnamed: R3.2, U1.3 (DIAG_EN)
unnamed: R2.2, U1.2 (EN)
unnamed: R9.1, U1.7 (ILIM)
unnamed: R5.2, R8.1, U1.6 (SNS)
VSense: J2.6, R11.2, R12.1

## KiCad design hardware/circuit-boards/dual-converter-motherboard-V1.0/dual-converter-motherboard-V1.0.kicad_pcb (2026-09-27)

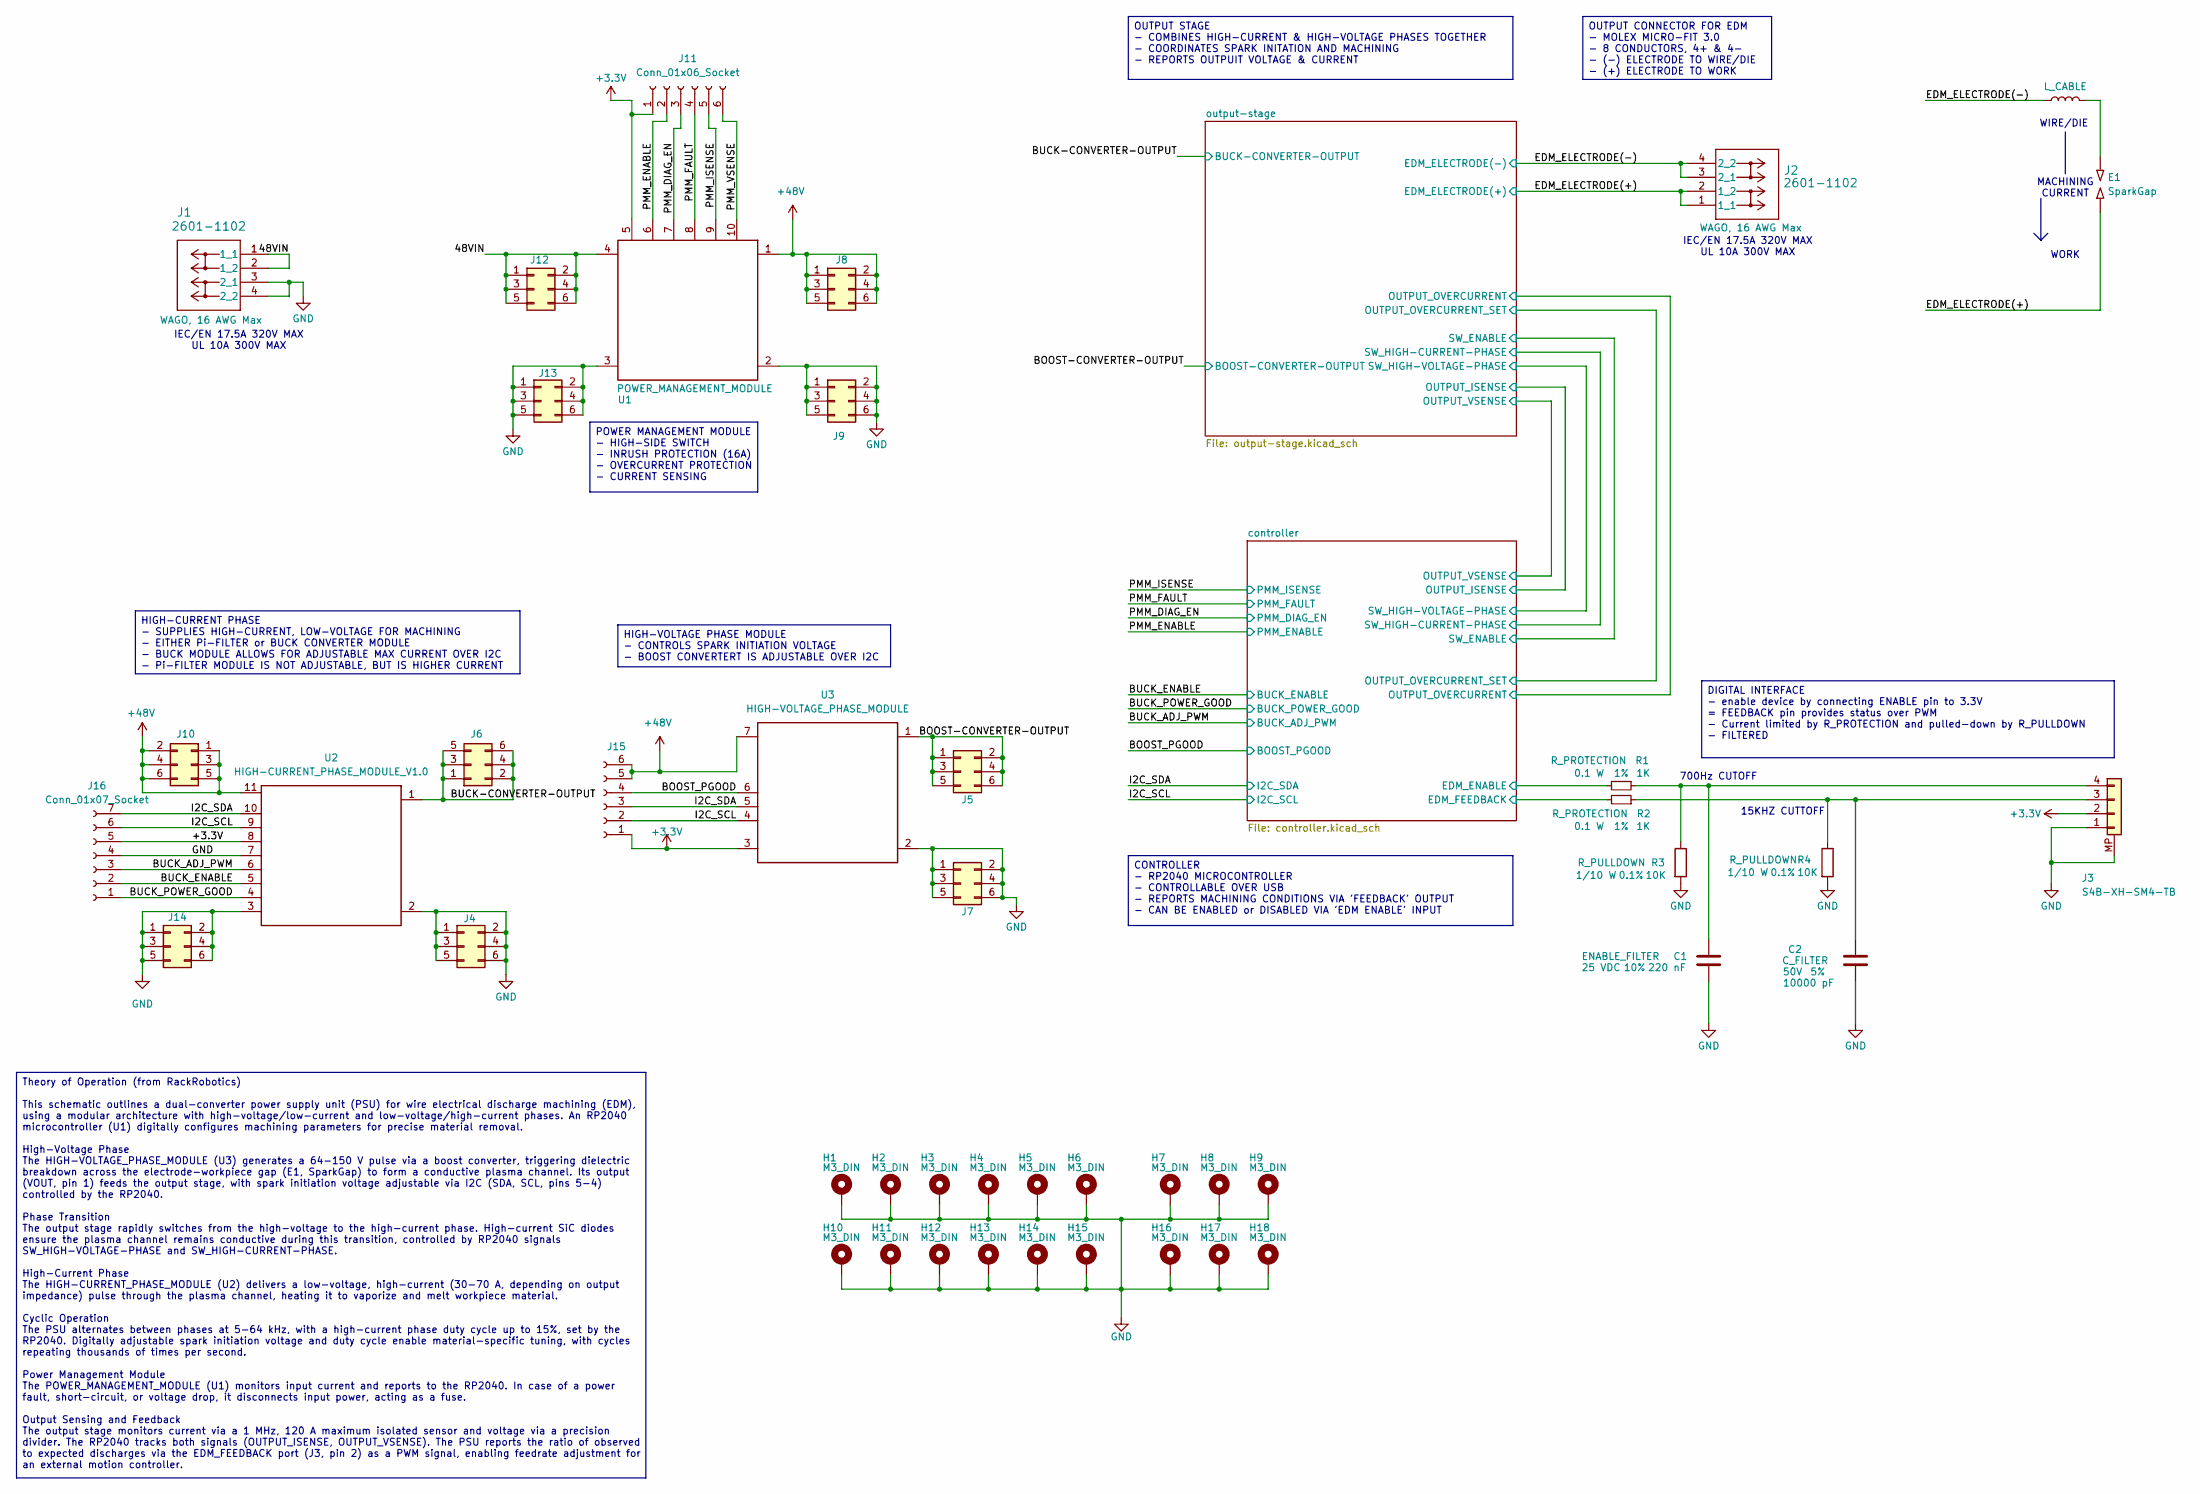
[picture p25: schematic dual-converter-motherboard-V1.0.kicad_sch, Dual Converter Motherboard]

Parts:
C1: 220 nF; C_0603_1608Metric; Tolerance 10%; Max Voltage 25 VDC; Manufacturer# AC0603KRX7R9BB224; LCSC Part # C726565
C2: 10000 pF; C_0603_1608Metric; Tolerance 5%; Max Voltage 50V; Manufacturer# CC0603JRX7R9BB103; LCSC Part # C115056
E1: SparkGap; NULL; Manufacturer# NULL; LCSC Part # NULL
H1, H2, H3, H4, H5, H6, H7, H8, H9, H10, H11, H12, H13, H14, H15, H16, H17, H18: M3_DIN; MountingHole_3.2mm_M3_DIN965_Pad_TopBottom; Manufacturer# NULL
J1, J2: 2601-1102; Manufacturer# 2601-1102; LCSC Part # C7509568
J3: S4B-XH-SM4-TB; Manufacturer# S4B-XH-SM4-TB; LCSC Part # C161861
J4, J5, J6, J7, J8, J9, J10, J12, J13, J14: Conn_02x03_Odd_Even; PinSocket_2x03_P2.54mm_Vertical
J11, J15: Conn_01x06_Socket; PinSocket_1x06_P2.54mm_Vertical
J16: Conn_01x07_Socket; PinSocket_1x07_P2.54mm_Vertical
L_CABLE1: L_CABLE
R1, R2: 1K; R_0603_1608Metric; Tolerance 1%; Manufacturer# RC0603FR-071KL; LCSC Part # C22548
R3, R4: 10K; R_0603_1608Metric; Tolerance 0.1%; Manufacturer# RC0603BR-0710KL; LCSC Part # C20161635
U1: POWER_MANAGEMENT_MODULE; POWER_MANAGEMENT_MODULE_FOOTPRINT_V1.0
U2: HIGH-CURRENT_PHASE_MODULE_V1.0; HIGH-CURRENT_PHASE_MODULE_FOOTPRINT_V1.0
U3: HIGH-VOLTAGE_PHASE_MODULE; HIGH-VOLTAGE_PHASE_MODULE_FOOTPRINT_V1.0

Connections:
+3.3V: J3.2, J11.1, J15.1, J16.5, U1.5, U2.8 (3.3VIN), U3.3 (GND); also elsewhere on the board
+48V: J8.1, J8.2, J8.3, J8.4, J8.5, J8.6, J10.1, J10.2, J10.3, J10.4, J10.5, J10.6, J15.5, J15.6, U1.1 (VOUT), U2.11 (48VIN), U3.7 (48VIN); also elsewhere on the board
/48VIN: J1.1 (1_1), J1.2 (1_2), J12.1, J12.2, J12.3, J12.4, J12.5, J12.6, U1.4 (VIN)
/BOOST-CONVERTER-OUTPUT: J5.1, J5.2, J5.3, J5.4, J5.5, J5.6, U3.1 (VOUT); also elsewhere on the board
/BOOST_PGOOD: J15.4, U3.6 (PGOOD); also elsewhere on the board
/BUCK-CONVERTER-OUTPUT: J6.1, J6.2, J6.3, J6.4, J6.5, J6.6, U2.1 (VOUT); also elsewhere on the board
/BUCK_ADJ_PWM: J16.3, U2.6 (PWM_ADJ); also elsewhere on the board
/BUCK_ENABLE: J16.2, U2.5 (ENABLE); also elsewhere on the board
/BUCK_POWER_GOOD: J16.1, U2.4 (PGOOD); also elsewhere on the board
/EDM_ELECTRODE(+): E1.1, J2.1 (1_1), J2.2 (1_2); also elsewhere on the board
/EDM_ELECTRODE(-): J2.3 (2_1), J2.4 (2_2), L_CABLE1.1; also elsewhere on the board
/I2C_SCL: J15.2, J16.6, U2.9 (SCL), U3.4 (SCL); also elsewhere on the board
/I2C_SDA: J15.3, J16.7, U2.10 (SDA), U3.5 (SDA); also elsewhere on the board
/PMM_DIAG_EN: J11.3, U1.7; also elsewhere on the board
/PMM_ENABLE: J11.2, U1.6; also elsewhere on the board
/PMM_FAULT: J11.4, U1.8; also elsewhere on the board
/PMM_ISENSE: J11.5, U1.9; also elsewhere on the board
/PMM_VSENSE: J11.6, U1.10
/controller/EDM_ENABLE: R1.2; also elsewhere on the board
/controller/EDM_FEEDBACK: R2.2; also elsewhere on the board
GND: C1.2, C2.2, H1.1, H2.1, H3.1, H4.1, H5.1, H6.1, H7.1, H8.1, H9.1, H10.1, H11.1, H12.1, H13.1, H14.1, H15.1, H16.1, H17.1, H18.1, J1.3 (2_1), J1.4 (2_2), J3.1, J3.MP, J4.1, J4.2, J4.3, J4.4, J4.5, J4.6, J7.1, J7.2, J7.3, J7.4, J7.5, J7.6, J9.1, J9.2, J9.3, J9.4, J9.5, J9.6, J13.1, J13.2, J13.3, J13.4, J13.5, J13.6, J14.1, J14.2, J14.3, J14.4, J14.5, J14.6, J16.4, R3.2, R4.2, U1.2, U1.3, U2.2 (GND), U2.3 (GND), U2.7 (GND), U3.2 (GND); also elsewhere on the board
unnamed: E1.2, L_CABLE1.2
unnamed: C2.1, J3.3, R2.1, R4.1
unnamed: C1.1, J3.4, R1.1, R3.1

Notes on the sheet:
IEC/EN 17.5A 320V MAX UL 10A 300V MAX
WORK
700Hz CUTOFF
MACHINING CURRENT
WIRE/DIE
15KHZ CUTTOFF
CONTROLLER - RP2040 MICROCONTROLLER - CONTROLLABLE OVER USB - REPORTS MACHINING CONDITIONS VIA 'FEEDBACK' OUTPUT - CAN BE ENABLED or DISABLED VIA 'EDM ENABLE' INPUT
HIGH-VOLTAGE PHASE MODULE - CONTROLS SPARK INITIATION VOLTAGE - BOOST CONVERTERT IS ADJUSTABLE OVER I2C
OUTPUT CONNECTOR FOR EDM - MOLEX MICRO-FIT 3.0 - 8 CONDUCTORS, 4+ & 4- - (-) ELECTRODE TO WIRE/DIE - (+) ELECTRODE TO WORK
HIGH-CURRENT PHASE - SUPPLIES HIGH-CURRENT, LOW-VOLTAGE FOR MACHINING - EITHER Pi-FILTER or BUCK CONVERTER MODULE - BUCK MODULE ALLOWS FOR ADJUSTABLE MAX CURRENT OVER I2C - Pi-FILTER MODULE IS NOT ADJUSTABLE, BUT IS HIGHER CURRENT
Theory of Operation (from RackRobotics) This schematic outlines a dual-converter power supply unit (PSU) for wire electrical discharge machining (EDM), using a modular architecture with high-voltage/low-current and low-voltage/high-current phases. An RP2040 microcontroller (U1) digitally configures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
OUTPUT STAGE - COMBINES HIGH-CURRENT & HIGH-VOLTAGE PHASES TOGETHER - COORDINATES SPARK INITATION AND MACHINING - REPORTS OUTPUIT VOLTAGE & CURRENT
POWER MANAGEMENT MODULE - HIGH-SIDE SWITCH - INRUSH PROTECTION (16A) - OVERCURRENT PROTECTION - CURRENT SENSING
DIGITAL INTERFACE - enable device by connecting ENABLE pin to 3.3V = FEEDBACK pin provides status over PWM - Current limited by R_PROTECTION and pulled-down by R_PULLDOWN - FILTERED

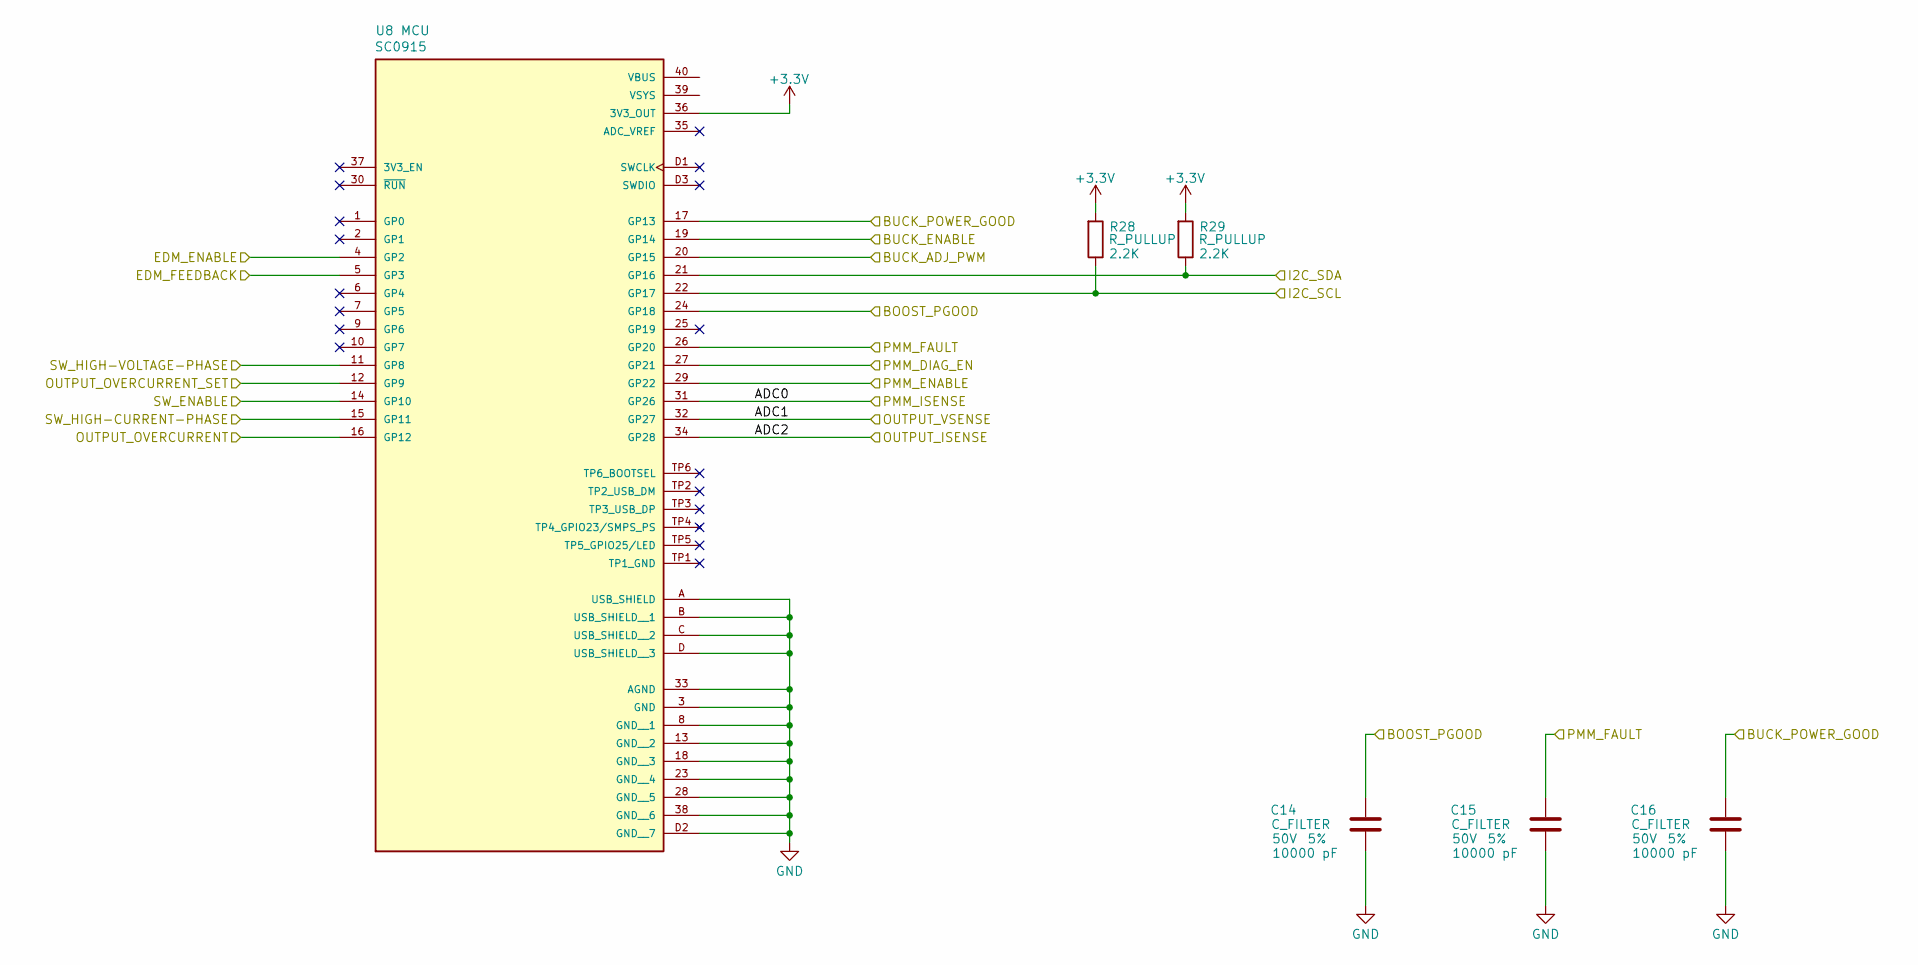
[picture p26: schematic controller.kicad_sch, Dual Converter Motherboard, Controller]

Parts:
C14, C15, C16: 10000 pF; C_0603_1608Metric; Tolerance 5%; Max Voltage 50V; Manufacturer# CC0603JRX7R9BB103; LCSC Part # C115056
R28, R29: 2.2K; R_0603_1608Metric; Tolerance 1%; Manufacturer# RC0603FR-132K2L; LCSC Part # C3032396
U8: SC0915; Manufacturer# SC0915; LCSC Part # C7203002

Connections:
+3.3V: R28.2, R29.2, U8.36 (3V3_OUT); also elsewhere on the board
/BOOST_PGOOD: C14.1, U8.24 (GP18); also elsewhere on the board
/BUCK_ADJ_PWM: U8.20 (GP15); also elsewhere on the board
/BUCK_ENABLE: U8.19 (GP14); also elsewhere on the board
/BUCK_POWER_GOOD: C16.1, U8.17 (GP13); also elsewhere on the board
/I2C_SCL: R28.1, U8.22 (GP17); also elsewhere on the board
/I2C_SDA: R29.1, U8.21 (GP16); also elsewhere on the board
/PMM_DIAG_EN: U8.27 (GP21); also elsewhere on the board
/PMM_ENABLE: U8.29 (GP22); also elsewhere on the board
/PMM_FAULT: C15.1, U8.26 (GP20); also elsewhere on the board
/PMM_ISENSE: U8.31 (GP26); also elsewhere on the board
/controller/ADC1: U8.32 (GP27); also elsewhere on the board
/controller/ADC2: U8.34 (GP28); also elsewhere on the board
/controller/EDM_ENABLE: U8.4 (GP2); also elsewhere on the board
/controller/EDM_FEEDBACK: U8.5 (GP3); also elsewhere on the board
/controller/OUTPUT_OVERCURRENT: U8.16 (GP12); also elsewhere on the board
/controller/OUTPUT_OVERCURRENT_SET: U8.12 (GP9); also elsewhere on the board
/controller/SW_ENABLE: U8.14 (GP10); also elsewhere on the board
/controller/SW_HIGH-CURRENT-PHASE: U8.15 (GP11); also elsewhere on the board
/controller/SW_HIGH-VOLTAGE-PHASE: U8.11 (GP8); also elsewhere on the board
GND: C14.2, C15.2, C16.2, U8.3 (GND), U8.8 (GND__1), U8.13 (GND__2), U8.18 (GND__3), U8.23 (GND__4), U8.28 (GND__5), U8.33 (AGND), U8.38 (GND__6), U8.A (USB_SHIELD), U8.B (USB_SHIELD__1), U8.C (USB_SHIELD__2), U8.D (USB_SHIELD__3), U8.D2 (GND__7); also elsewhere on the board

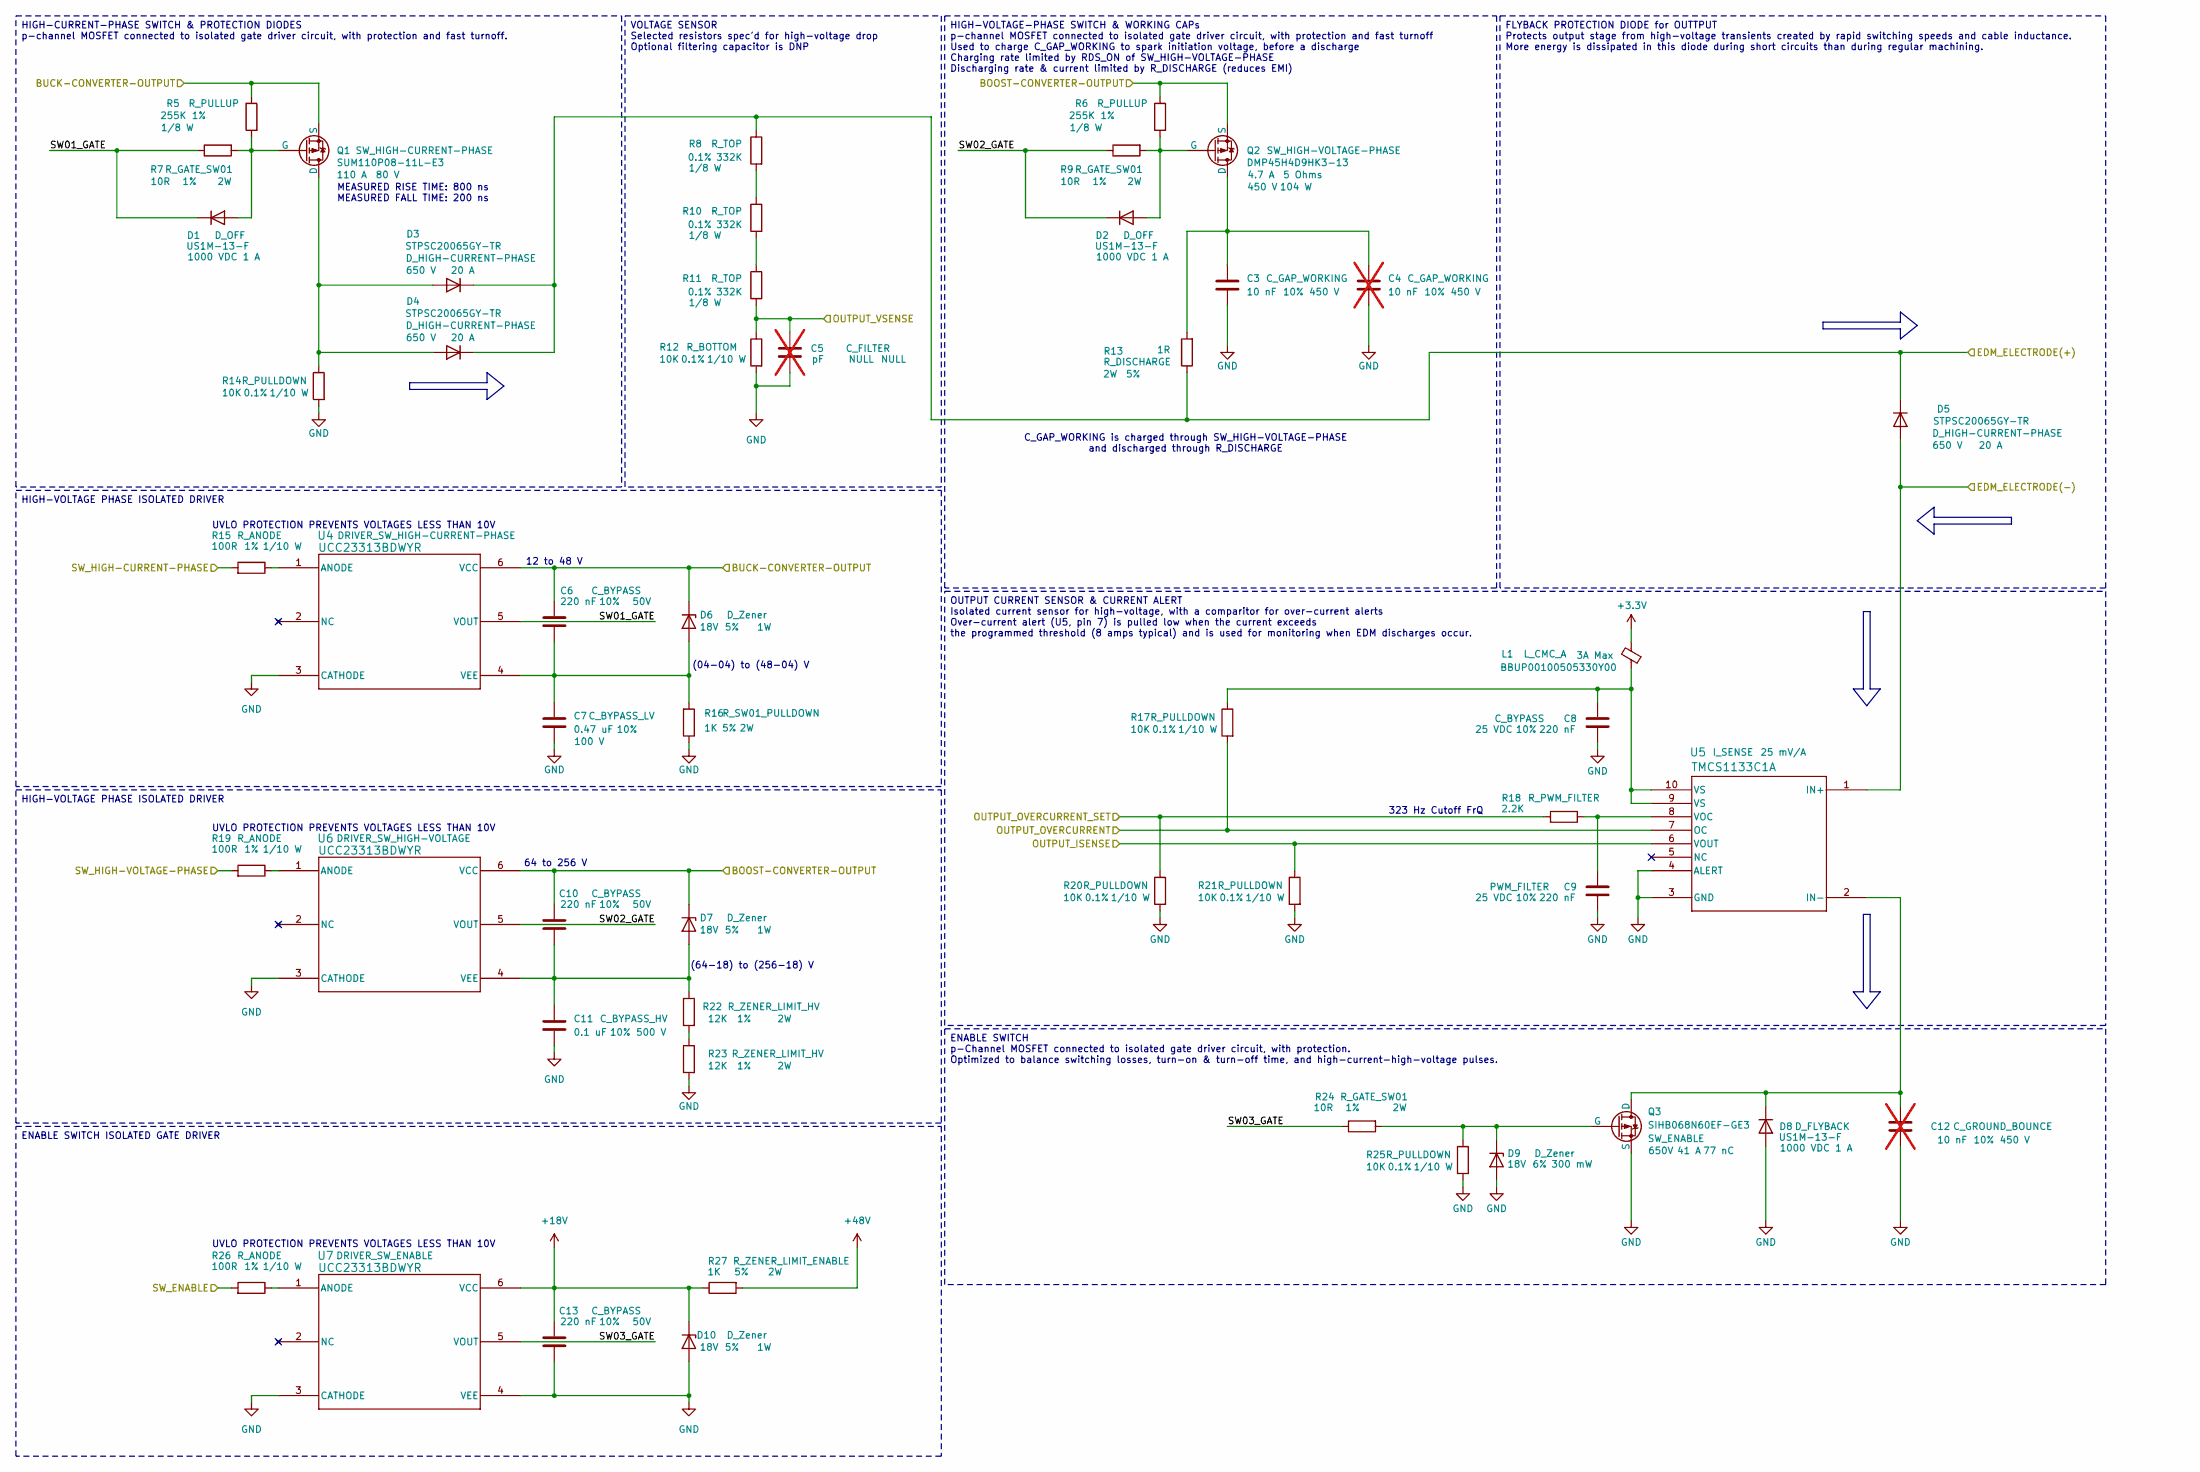
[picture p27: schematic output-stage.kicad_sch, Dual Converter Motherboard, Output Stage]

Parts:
C3: 10 nF; C_0805_2012Metric; Tolerance 10%; Max Voltage 450 V; Manufacturer# C2012X7T2W103K085AA; LCSC Part # C342860
C4, C12: 10 nF; C_0805_2012Metric; Tolerance 10%; Max Voltage 450 V; Manufacturer# C2012X7T2W103K085AA; LCSC Part # C342860; not fitted
C5: pF; C_0603_1608Metric; Tolerance NULL; Max Voltage NULL; Manufacturer# NULL; LCSC Part # NULL; not fitted
C6, C10, C13: 220 nF; C_0603_1608Metric; Tolerance 10%; Max Voltage 50V; Manufacturer# AC0603KRX7R9BB224; LCSC Part # C726565
C7: 0.47 uF; C_0805_2012Metric; Tolerance 10%; Max Voltage 100 V; Manufacturer# CC0805KKX7R0BB474; LCSC Part # C596323
C8, C9: 220 nF; C_0603_1608Metric; Tolerance 10%; Max Voltage 25 VDC; Manufacturer# AC0603KRX7R9BB224; LCSC Part # C726565
C11: 0.1 uF; C_1210_3225Metric; Tolerance 10%; Max Voltage 500 V; Manufacturer# C1210C104KCRACTU; LCSC Part # C141218
D1, D2, D8: US1M-13-F; D_SMA; Tolerance NULL; Manufacturer# US1M-13-F; LCSC Part # C99333
D3, D4, D5: STPSC20065GY-TR; Tolerance NULL; Manufacturer# STPSC20065GY-TR; LCSC Part # C2965441
D6, D7, D10: D_Zener; D_SMA; Zener Voltage 18V; Tolerance 5%; Manufacturer# SMAZ18-13-F; LCSC Part # C110525
D9: D_Zener; D_SOD-323; Zener Voltage 18V; Tolerance 6%; Manufacturer# MM3Z18VT1G; LCSC Part # C82043
L1: BBUP00100505330Y00; L_0402_1005Metric; Manufacturer# BLM15AX100SN1D; LCSC Part # C668299
Q1: SUM110P08-11L-E3; Max Voltage 80 V; Manufacturer# SUM110P08-11L-E3; LCSC Part # C2838509
Q2: DMP45H4D9HK3-13; Max Voltage 450 V; Manufacturer# DMP45H4D9HK3-13
Q3: SIHB068N60EF-GE3; TO-263-2; Max Voltage 650V; Manufacturer# SIHB068N60EF-GE3; LCSC Part # C3009875
R5, R6: 255K; R_0603_1608Metric; Tolerance 1%; Manufacturer# RC0603FR-07255KL; LCSC Part # C295887
R7, R9, R24: 10R; R_2512_6332Metric; Tolerance 1%; Manufacturer# SR2512JK-7W10RL
R8, R10, R11: 332K; R_0805_2012Metric; Tolerance 0.1%; Manufacturer# RT0805BRD07332KL
R12, R14, R17, R20, R21, R25: 10K; R_0603_1608Metric; Tolerance 0.1%; Manufacturer# RC0603BR-0710KL; LCSC Part # C20161635
R13: 1R; R_2512_6332Metric; Tolerance 5%; Manufacturer# CRM2512-JW-1R0ELF; LCSC Part # C840599
R15, R19, R26: 100R; R_0603_1608Metric; Tolerance 1%; Manufacturer# RC0603FR-10100RL; LCSC Part # C20161635
R16, R27: 1K; R_2512_6332Metric; Tolerance 5%; Manufacturer# RES 1K OHM 5% 2W 2512; LCSC Part # C7038808
R18: 2.2K; R_0603_1608Metric; Tolerance 1%; Manufacturer# RC0603FR-132K2L; LCSC Part # C3032396
R22, R23: 12K; R_2512_6332Metric; Tolerance 1%; Manufacturer# CRGP2512F12K; LCSC Part # C2082818
U4, U6, U7: UCC23313BDWYR; Tolerance NULL; Manufacturer# UCC23313BDWYR; LCSC Part # C2868027
U5: TMCS1133C1A; TMCS1133C3AQDVGR; Tolerance 1%; Manufacturer# TMCS1133C1AQDVGR; LCSC Part # C32266987

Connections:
+3.3V: L1.2; also elsewhere on the board
+18V: C13.1, D10.1 (K), R27.1, U7.6 (VCC)
+48V: R27.2; also elsewhere on the board
/BOOST-CONVERTER-OUTPUT: C10.1, D7.1 (K), Q2.3 (S), R6.1, U6.6 (VCC); also elsewhere on the board
/BUCK-CONVERTER-OUTPUT: C6.1, D6.1 (K), Q1.3 (S), R5.1, U4.6 (VCC); also elsewhere on the board
/EDM_ELECTRODE(+): D3.1 (K), D4.1 (K), D5.1 (K), R8.1, R13.1; also elsewhere on the board
/EDM_ELECTRODE(-): D5.2 (A), U5.1 (IN+); also elsewhere on the board
/controller/ADC1: C5.1, R11.2, R12.1; also elsewhere on the board
/controller/ADC2: R21.1, U5.6 (VOUT); also elsewhere on the board
/controller/OUTPUT_OVERCURRENT: R17.2, U5.7 (OC); also elsewhere on the board
/controller/OUTPUT_OVERCURRENT_SET: R18.1, R20.1; also elsewhere on the board
/controller/SW_ENABLE: R26.2; also elsewhere on the board
/controller/SW_HIGH-CURRENT-PHASE: R15.2; also elsewhere on the board
/controller/SW_HIGH-VOLTAGE-PHASE: R19.2; also elsewhere on the board
/output-stage/SW01_GATE: D1.1 (K), R7.1, U4.5 (VOUT)
/output-stage/SW02_GATE: D2.1 (K), R9.1, U6.5 (VOUT)
/output-stage/SW03_GATE: R24.1, U7.5 (VOUT)
GND: C3.2, C4.2, C5.2, C7.2, C8.2, C9.2, C11.2, C12.2, C13.2, D8.2 (A), D9.2 (A), D10.2 (A), Q3.3 (S), R12.2, R14.2, R16.1, R20.2, R21.2, R23.2, R25.2, U4.3 (CATHODE), U5.3 (GND), U5.4 (ALERT), U6.3 (CATHODE), U7.3 (CATHODE), U7.4 (VEE); also elsewhere on the board
unnamed: C8.1, L1.1, R17.1, U5.9 (VS), U5.10 (VS)
unnamed: D1.2 (A), Q1.2 (G), R5.2, R7.2
unnamed: D2.2 (A), Q2.2 (G), R6.2, R9.2
unnamed: D3.2 (A), D4.2 (A), Q1.1 (D), R14.1
unnamed: C6.2, C7.1, D6.2 (A), R16.2, U4.4 (VEE)
unnamed: C10.2, C11.1, D7.2 (A), R22.1, U6.4 (VEE)
unnamed: C12.1, D8.1 (K), Q3.2 (D), U5.2 (IN-)
unnamed: D9.1 (K), Q3.1 (G), R24.2, R25.1
unnamed: C3.1, C4.1, Q2.1 (D), R13.2
unnamed: R8.2, R10.1
unnamed: R10.2, R11.1
unnamed: R22.2, R23.1
unnamed: R15.1, U4.1 (ANODE)
unnamed: C9.1, R18.2, U5.8 (VOC)
unnamed: R19.1, U6.1 (ANODE)
unnamed: R26.1, U7.1 (ANODE)

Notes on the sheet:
UVLO PROTECTION PREVENTS VOLTAGES LESS THAN 10V
C_GAP_WORKING is charged through SW_HIGH-VOLTAGE-PHASE and discharged through R_DISCHARGE
323 Hz Cutoff FrQ
(04-04) to (48-04) V
12 to 48 V
(64-18) to (256-18) V
64 to 256 V
MEASURED RISE TIME: 800 ns MEASURED FALL TIME: 200 ns
FLYBACK PROTECTION DIODE for OUTTPUT Protects output stage from high-voltage transients created by rapid switching speeds and cable inductance. More energy is dissipated in this diode during short circuits than during regular machining.
HIGH-VOLTAGE PHASE ISOLATED DRIVER
ENABLE SWITCH ISOLATED GATE DRIVER
ENABLE SWITCH p-Channel MOSFET connected to isolated gate driver circuit, with protection. Optimized to balance switching losses, turn-on & turn-off time, and high-current-high-voltage pulses.
HIGH-VOLTAGE-PHASE SWITCH & WORKING CAPs p-channel MOSFET connected to isolated gate driver circuit, with protection and fast turnoff Used to charge C_GAP_WORKING to spark initiation voltage, before a discharge Charging rate limited by RDS_ON of SW_HIGH-VOLTAGE-PHASE Discharging rate & current limi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
OUTPUT CURRENT SENSOR & CURRENT ALERT Isolated current sensor for high-voltage, with a comparitor for over-current alerts Over-current alert (U5, pin 7) is pulled low when the current exceeds the programmed threshold (8 amps typical) and is used for monitoring when EDM discharges occur.
VOLTAGE SENSOR Selected resistors spec'd for high-voltage drop Optional filtering capacitor is DNP
HIGH-CURRENT-PHASE SWITCH & PROTECTION DIODES p-channel MOSFET connected to isolated gate driver circuit, with protection and fast turnoff.

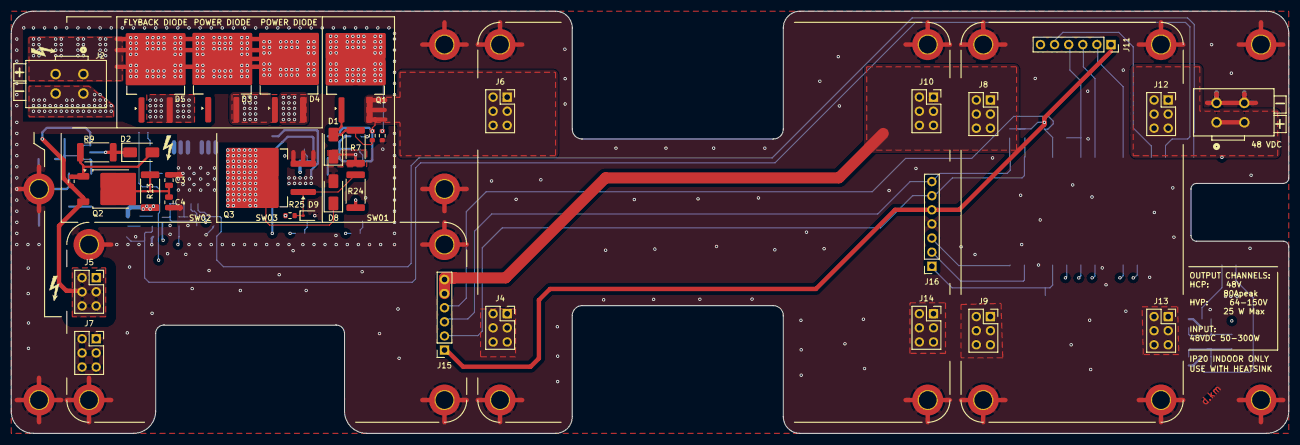
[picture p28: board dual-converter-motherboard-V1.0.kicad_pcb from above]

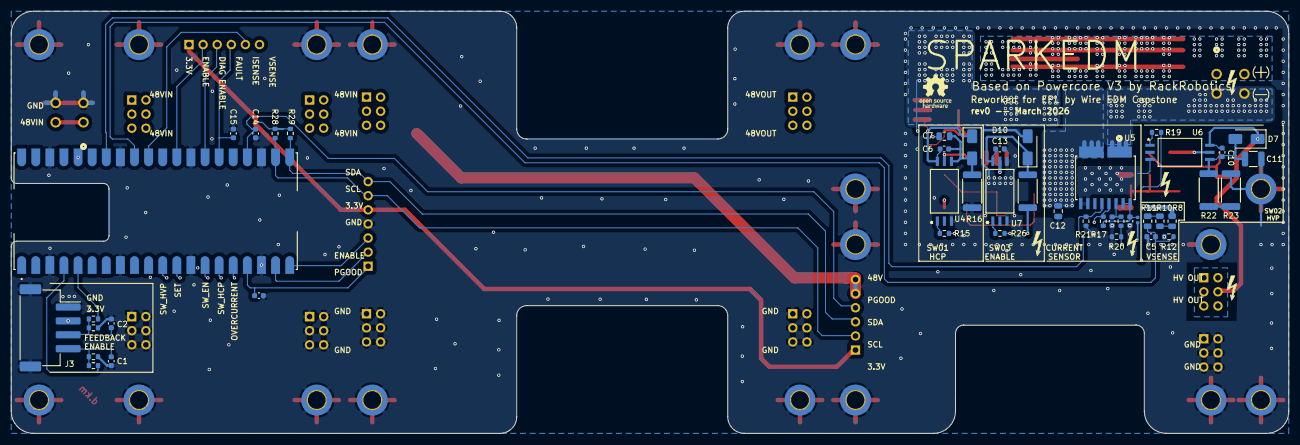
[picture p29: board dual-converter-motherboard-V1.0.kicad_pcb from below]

Board: 6 copper layers, 230.0 x 76.0 mm, 98 parts (45 on the bottom side), 49 nets.

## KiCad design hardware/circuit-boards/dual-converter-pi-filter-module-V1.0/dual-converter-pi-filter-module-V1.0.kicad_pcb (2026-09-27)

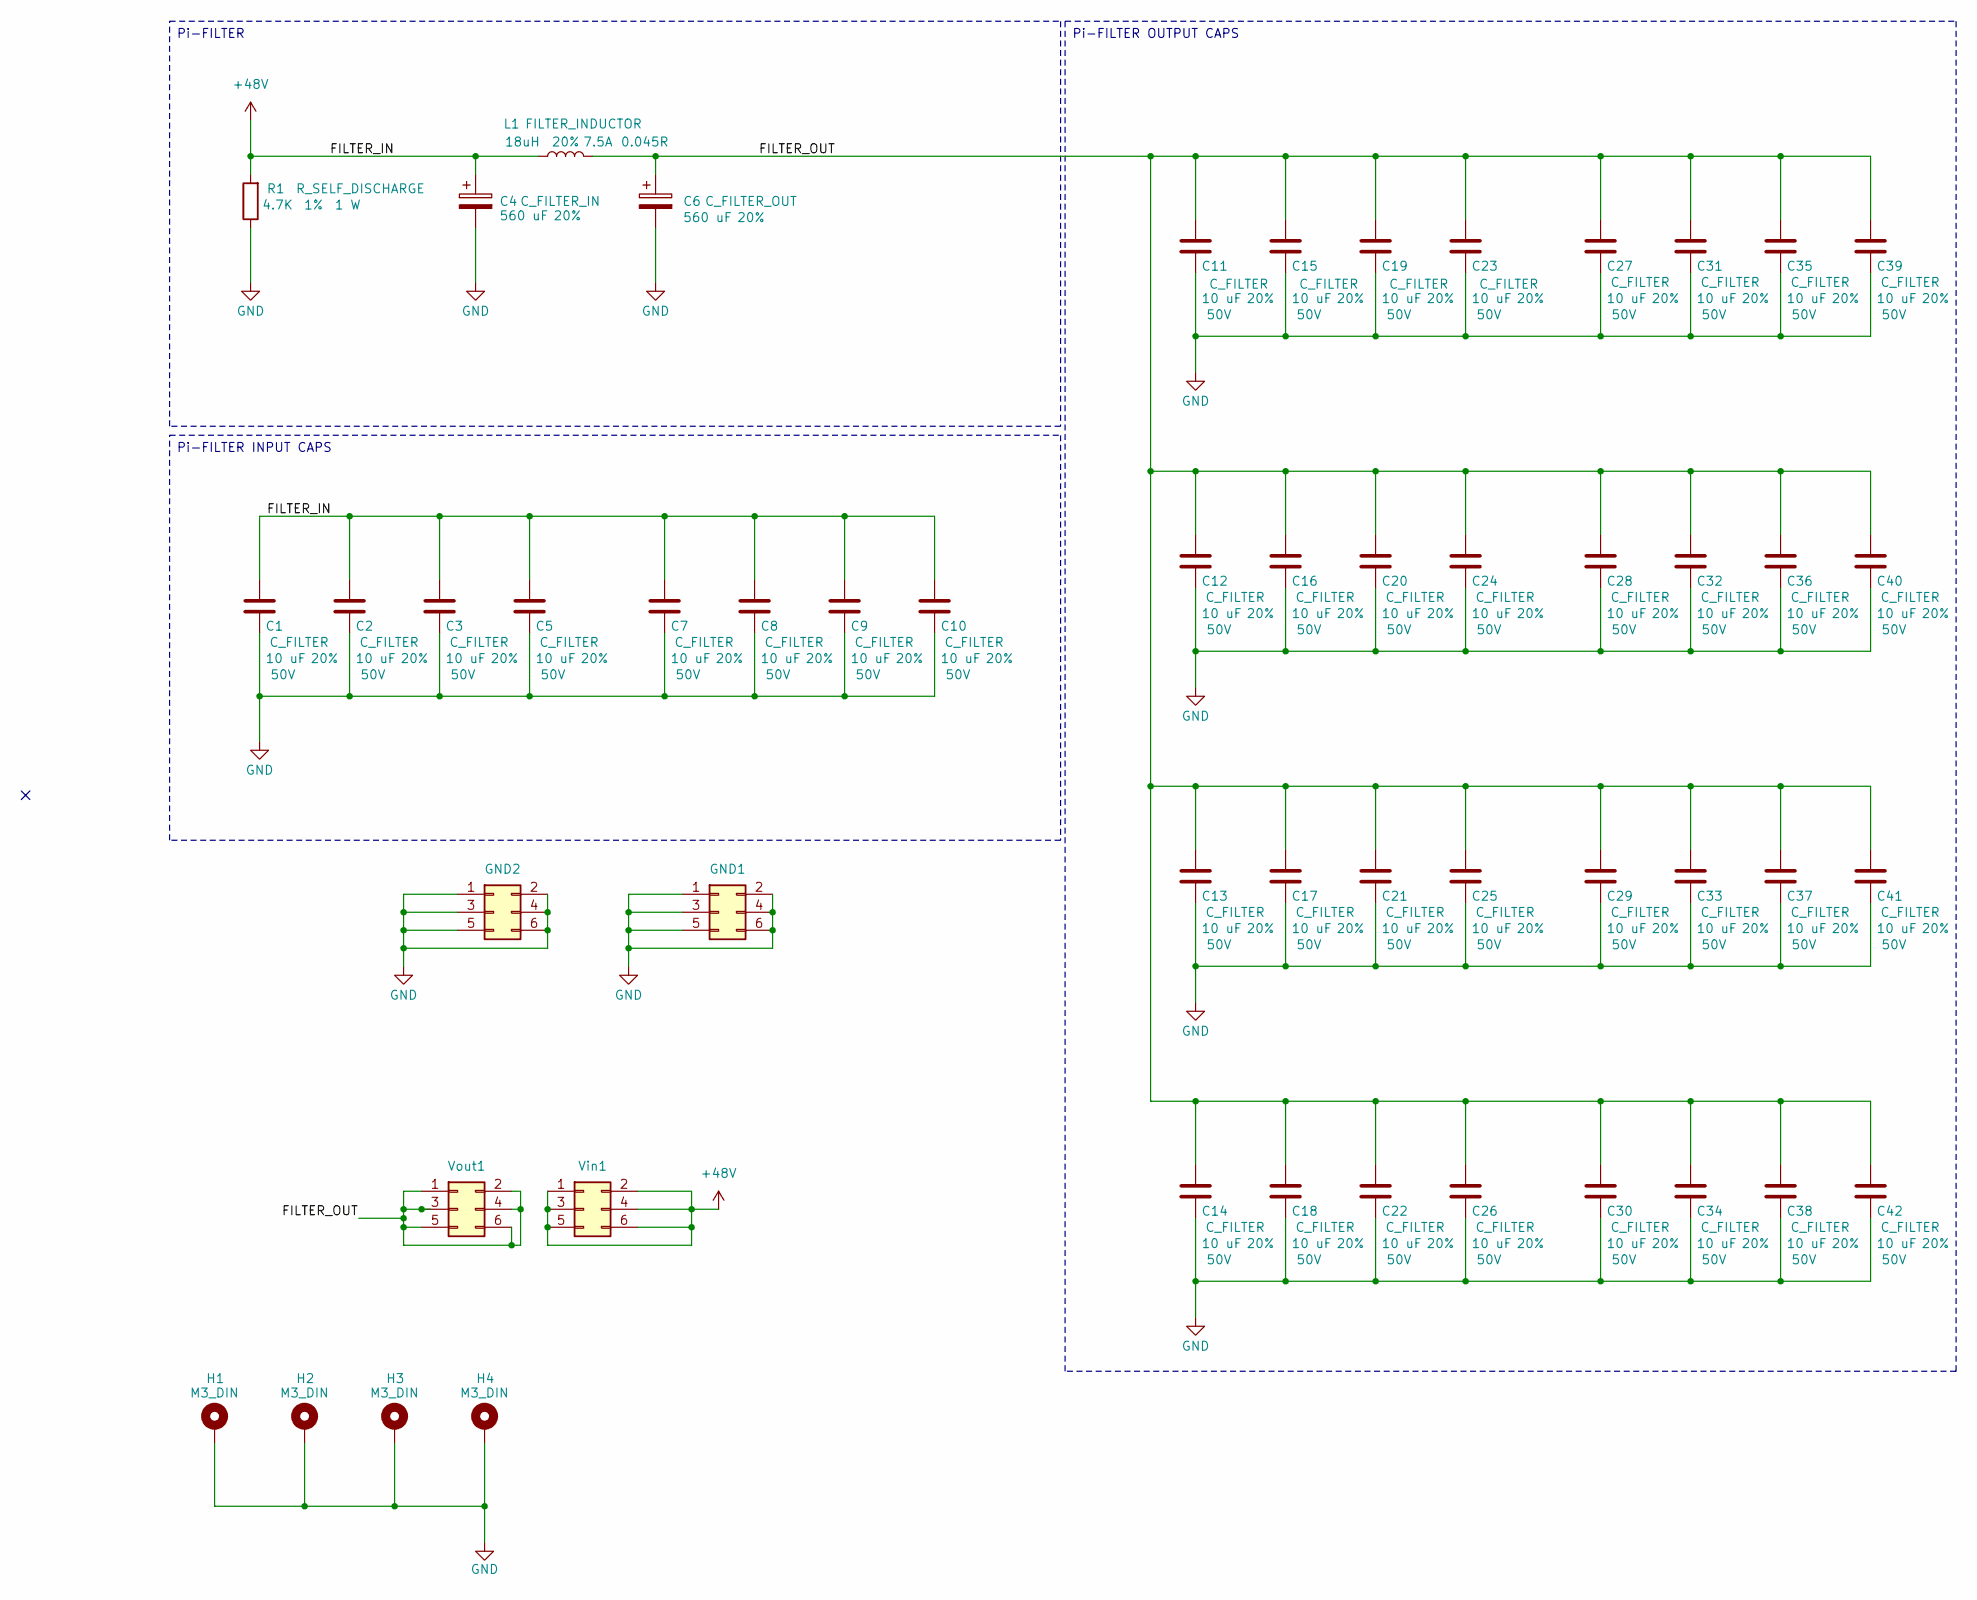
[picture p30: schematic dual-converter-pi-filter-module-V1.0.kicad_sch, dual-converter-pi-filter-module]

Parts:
C1, C2, C3, C5, C7, C8, C9, C10, C11, C12, C13, C14, C15, C16, C17, C18, C19, C20, C21, C22, C23, C24, C25, C26, C27, C28, C29, C30, C31, C32, C33, C34, C35, C36, C37, C38, C39, C40, C41, C42: 10 uF; C_1206_3216Metric; Tolerance 20%; Max Voltage 50V; Manufacturer# CL31A106MBHNNNE; LCSC Part # C96600
C4, C6: 560 uF; PHA225; Tolerance 20%; Manufacturer# PHA225MLP3560QE4; LCSC Part # C3274794
GND1, GND2: Conn_02x03_Odd_Even; PinHeader_2x03_P2.54mm_Vertical
H1, H2, H3, H4: M3_DIN; MountingHole_3.2mm_M3_DIN965_Pad_TopBottom; Manufacturer# NULL
L1: 18uH; SRP1245A; Tolerance 20%; Current Rating 7.5A; Manufacturer# SRP1245A-180M; LCSC Part # C5926042
R1: 4.7K; R_2512_6332Metric; Tolerance 1%; Manufacturer# RC2512JK-074K7L; LCSC Part # C878291
Vin1: Conn_02x03_Odd_Even; PinHeader_2x03_P2.54mm_Vertical
Vout1: Conn_02x03_Odd_Even; PinHeader_2x03_P2.54mm_Vertical

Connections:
+48V: C1.1, C2.1, C3.1, C4.1, C5.1, C7.1, C8.1, C9.1, C10.1, L1.1, R1.2, Vin1.1, Vin1.2, Vin1.3, Vin1.4, Vin1.5, Vin1.6
/FILTER_OUT: C6.1, C11.1, C12.1, C13.1, C14.1, C15.1, C16.1, C17.1, C18.1, C19.1, C20.1, C21.1, C22.1, C23.1, C24.1, C25.1, C26.1, C27.1, C28.1, C29.1, C30.1, C31.1, C32.1, C33.1, C34.1, C35.1, C36.1, C37.1, C38.1, C39.1, C40.1, C41.1, C42.1, L1.2, Vout1.1, Vout1.2, Vout1.3, Vout1.4, Vout1.5, Vout1.6
GND: C1.2, C2.2, C3.2, C4.2, C5.2, C6.2, C7.2, C8.2, C9.2, C10.2, C11.2, C12.2, C13.2, C14.2, C15.2, C16.2, C17.2, C18.2, C19.2, C20.2, C21.2, C22.2, C23.2, C24.2, C25.2, C26.2, C27.2, C28.2, C29.2, C30.2, C31.2, C32.2, C33.2, C34.2, C35.2, C36.2, C37.2, C38.2, C39.2, C40.2, C41.2, C42.2, GND1.1, GND1.2, GND1.3, GND1.4, GND1.5, GND1.6, GND2.1, GND2.2, GND2.3, GND2.4, GND2.5, GND2.6, H1.1, H2.1, H3.1, H4.1, R1.1

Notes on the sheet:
Pi-FILTER INPUT CAPS
Pi-FILTER
Pi-FILTER OUTPUT CAPS

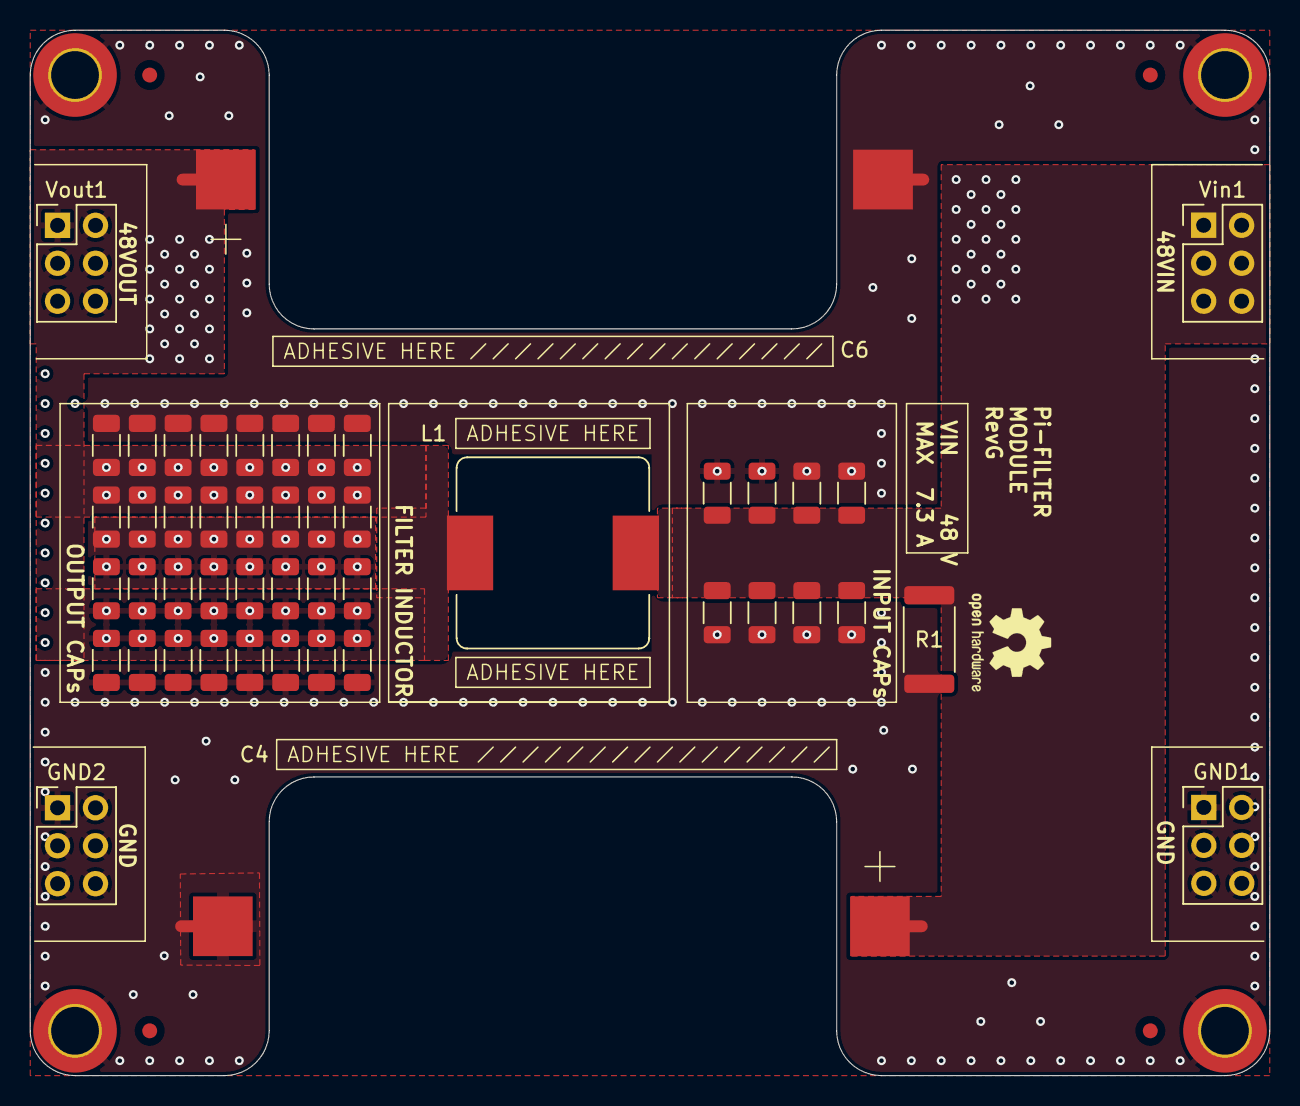
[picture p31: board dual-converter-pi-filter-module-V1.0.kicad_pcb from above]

Board: 4 copper layers, 83.0 x 70.0 mm, 52 parts (0 on the bottom side), 3 nets.

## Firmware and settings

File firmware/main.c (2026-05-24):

/* main.c
 *
 * EPL WPS firmware entry point. Owns the runtime context, the boost
 * converter handle, and the system-wide GPIO IRQ dispatcher. All other
 * state lives file-static inside its respective module.
 *
 * Boot sequence:
 *   ctx_init -> cmd_init -> output_init -> pmm_init -> sensors_init ->
 *   boost create -> calibrate input current (PMM off) ->
 *   pmm_enable_and_wait -> calibrate output current ->
 *   register GPIO dispatcher -> fault_init / fault_attach_irqs ->
 *   output_attach_isr -> HV-only output stage -> boost_cal_build ->
 *   MAX-safe HV check -> output_stage_disable -> IDLE.
 *
 * Main loop, in order:
 *   1. Service any pending fault.
 *   2. cmd_poll (every iteration).
 *   3. Periph tick every PERIPH_MGMT_INTERVAL_MS: PMM sample, power-out-
 *      of-range check, EDM_ENABLE_PIN -> state, feedback-duty update.
 *   4. State dispatch: OPERATING preps mode lazily then runs the per-
 *      tick mode body; IDLE disables output and sleeps 10 ms.
 *   5. cmd_tick (periodic telemetry).
 */

#include <stdio.h>
#include <stdint.h>
#include <stdbool.h>

#include "pico/stdlib.h"
#include "hardware/gpio.h"
#include "hardware/irq.h"

#include "config.h"
#include "src/types.h"
#include "src/ctx.h"
#include "src/cmd.h"
#include "src/sensors.h"
#include "src/pmm.h"
#include "src/boost.h"
#include "src/output.h"
#include "src/fault.h"

/* --- File-static state ------------------------------------------------ */

static main_ctx_t        g_ctx;
static boost_dpot_t     *g_boost_dpot;
static boost_cal_table_t g_boost_cal;

/* --- GPIO IRQ dispatcher --------------------------------------------- */

/* Single system-wide GPIO callback. The RP2040 SDK only allows one;
 * each module exposes a thin _isr() entry that this dispatcher calls
 * based on the firing pin. */
static void gpio_irq_dispatch(uint gpio, uint32_t events)
{
    (void)events;
    if      (gpio == PMM_FAULT_PIN)          fault_pmm_isr();
    else if (gpio == BOOST_PGOOD_PIN)        fault_boost_pgood_isr();
    else if (gpio == OUTPUT_OVERCURRENT_PIN) output_overcurrent_isr();
}

/* --- Boot helpers ---------------------------------------------------- */

static void status_led_init(void)
{
    gpio_init(STATUS_LED_PIN);
    gpio_put(STATUS_LED_PIN, false);
    gpio_set_dir(STATUS_LED_PIN, GPIO_OUT);
}

static void edm_enable_pin_init(void)
{
    gpio_init(EDM_ENABLE_PIN);
    gpio_set_dir(EDM_ENABLE_PIN, GPIO_IN);
}

/* Scan the cal table; trip a non-recoverable HV-setup fault if any
 * calibrated DPOT position produced a voltage above the safe ceiling.
 * Trips on an empty / failed cal table too (calibrated == false). */
static void verify_boost_cal_safe(void)
{
    if (!g_boost_cal.calibrated) {
        printf("ERROR: boost cal table not built\n");
        fault_trip(HIGH_VOLTAGE_PHASE_SETUP_FAULT);
        return;
    }
    float max_v = 0.0f;
    for (uint8_t i = 0; i < g_boost_cal.count; i++) {
        if (g_boost_cal.entries[i].voltage > max_v) {
            max_v = g_boost_cal.entries[i].voltage;
        }
    }
    if (max_v > (float)MAX_HIGH_VOLTAGE_PHASE_VOLTS) {
        printf("ERROR: boost cal max voltage %.2f V exceeds safe ceiling %d V\n",
               (double)max_v, MAX_HIGH_VOLTAGE_PHASE_VOLTS);
        fault_trip(HIGH_VOLTAGE_PHASE_SETUP_FAULT);
    }
    if (max_v < (float)MIN_HIGH_VOLTAGE_PHASE_VOLTS) {
        printf("ERROR: boost cal max voltage %.2f V lower than minimum %d V\n",
               (double)max_v, MIN_HIGH_VOLTAGE_PHASE_VOLTS);
        fault_trip(HIGH_VOLTAGE_PHASE_SETUP_FAULT);
    }
}

/* --- Mode preparation (OPERATING entry) ----------------------------- */

static void prepare_isofreq_mode(void)
{
    boost_set_voltage(g_boost_dpot, &g_boost_cal,
                      g_ctx.params.init_voltage,
                      (uint32_t)BOOST_CONVERTER_RAMP_SPACING_MS);
    if (!output_setup_isofreq(&g_ctx, &g_boost_cal)) {
        fault_trip(HIGH_VOLTAGE_PHASE_SETUP_FAULT);
    }
}

static void prepare_edge_mode(void)
{
    boost_set_voltage(g_boost_dpot, &g_boost_cal,
                      (float)MIN_HIGH_VOLTAGE_PHASE_VOLTS,
                      (uint32_t)BOOST_CONVERTER_RAMP_SPACING_MS);
    if (!output_setup_edge(&g_boost_cal)) {
        fault_trip(HIGH_VOLTAGE_PHASE_SETUP_FAULT);
    }
}

/* --- Periph tick (every PERIPH_MGMT_INTERVAL_MS) -------------------- */

static void periph_tick(void)
{
    sensors_sample_input_current();
    if (sensors_avg_input_current_amps() > MAX_SAFE_INPUT_CURRENT) {
        fault_trip(POWER_OUT_OF_RANGE_FAULT);
        return;
    }

    ctx_set_state(&g_ctx,
                  gpio_get(EDM_ENABLE_PIN) ? OPERATING : IDLE);

    if (g_ctx.state == OPERATING) {
        float power_w = sensors_avg_input_current_amps() * INPUT_SUPPLY_VOLTAGE;
        float ratio   = power_w / MAX_INPUT_POWER_SETPOINT_WATTS;
        /* Encode power ratio as feedback frequency: MAX = full power,
         * MIN = no power. set_ratio clamps internally. */
        output_feedback_set_ratio(ratio);
    } else {
        output_feedback_disable();
    }
}

/* --- Entry point ----------------------------------------------------- */

int main(void)
{
    /* 1. Runtime context. State starts as STARTUP. */
    ctx_init(&g_ctx);

    /* 2. USB-CDC up first so the rest of boot can log. */
    cmd_init();
    printf("Software Version: %s\n", "rev0");

    /* 3. STATUS LED off until boot completes. */
    status_led_init();

    /* 4. EDM_ENABLE input. */
    edm_enable_pin_init();

    /* 5. Output stage: cache PWM slices, configure feedback PWM,
     *    drive switches into safe-OFF SIO state. */
    output_init();

    /* 6. PMM GPIOs: ENABLE deasserted, DIAG_EN asserted, FAULT as input.
     *    Must precede sensors_calibrate_input_current — calibrating with
     *    the high-side switch off captures the true zero-current offset. */
    pmm_init();

    /* 7. ADC peripheral and three sensor pins. */
    sensors_init();

    /* 8. Boost DPOT handle + I2C wiring. Cal table starts uncalibrated. */
    g_boost_dpot = boost_dpot_create(I2C_PORT, DPOT_ADDR, DPOT_REG);
    boost_setup_i2c(g_boost_dpot, I2C_SDA_PIN, I2C_SCL_PIN, I2C_BAUD_RATE_HZ);
    cmd_set_boost_ctx(g_boost_dpot, &g_boost_cal);

    /* 9. Calibrate input current with the high-side switch still off. */
    printf("Calibrating PMM input-current zero offset...\n");
    sensors_calibrate_input_current();

    /* 10. Bring up the PMM and wait for inrush to settle. */
    printf("Enabling PMM...\n");
    pmm_enable_and_wait();

    /* 11. Output current zero-cal (HV stage idle, no discharge yet). */
    printf("Calibrating output-current zero offset...\n");
    sensors_calibrate_output_current();

    /* 12. Register the system-wide GPIO callback once. Per-pin enables
     *     come from fault_attach_irqs and output_attach_isr; they use
     *     gpio_set_irq_enabled (no callback arg) which attaches to the
     *     dispatcher we just registered. */
    gpio_set_irq_callback(gpio_irq_dispatch);
    irq_set_enabled(IO_IRQ_BANK0, true);

    /* 13. Fault module: state reset, BOOST_PGOOD pin direction, edge
     *     IRQs armed. */
    fault_init();
    fault_attach_irqs();

    /* 14. Output ISR binding + OUTPUT_OVERCURRENT edge IRQ. */
    output_attach_isr(&g_ctx);

    /* 15. Hold HV stage active so the boost can be calibrated. */
    printf("Holding HV phase active for boost calibration...\n");
    output_stage_setup(0.0f, 10000,
                       (float)DEFAULT_OUTPUT_CURRENT_THRESHOLD_A,
                       false, true,
                       (float)EDM_ISOFREQ_HV_PULSE_ON_TIME_US,
                       (float)EDM_ISOFREQ_HV_PWM_OFFSET);

    /* 16. Sweep DPOT positions and record the wiper-to-voltage table. */
    printf("Building boost-converter DPOT voltage table...\n");
    boost_cal_status_t cal_status =
        boost_cal_build(g_boost_dpot, &g_boost_cal, 8, 20);
    if (cal_status != BOOST_CAL_OK) {
        printf("ERROR: boost_cal_build failed (status=%d)\n", (int)cal_status);
    }

    /* 17. Trip if the boost can produce voltages above the safe ceiling
     *     or if the cal table didn't get built. Non-recoverable: the
     *     main loop's first iteration will see fault_pending and spin
     *     in fault_handle until the operator issues RESET_DEVICE. */
    verify_boost_cal_safe();

    /* 18. Drop output stage now that calibration is done. */
    output_stage_disable();

    /* 19. Boot complete (or boot failed). */
    if (fault_pending()) {
        printf("ERROR: setup failed; fault pending, awaiting recovery\n");
    } else {
        gpio_put(STATUS_LED_PIN, true);
        printf("OK: Setup complete\n");
        ctx_set_state(&g_ctx, IDLE);
    }

    /* --- Main loop --------------------------------------------------- */

    while (1) {
        uint32_t now_ms = to_ms_since_boot(get_absolute_time());

        /* 1. Pending fault: hand control to the fault handler. */
        if (fault_pending()) {
            ctx_set_state(&g_ctx, FAULT);
            fault_handle(&g_ctx, cmd_poll);
            ctx_reset_discharge_stats(&g_ctx);
            ctx_set_state(&g_ctx, IDLE);
            continue;
        }

        /* 2. Operator commands every iteration. */
        cmd_poll(&g_ctx);

        /* 3. Periph tick at fixed cadence. */
        if (now_ms - g_ctx.last_periph_tick_ms
            >= (uint32_t)PERIPH_MGMT_INTERVAL_MS) {
            periph_tick();
            g_ctx.last_periph_tick_ms = now_ms;
        }

        /* 4. State dispatch. */
        switch (g_ctx.state) {
        case OPERATING:
            if (!g_ctx.mode_prep_done) {
                if (g_ctx.mode == EDM_ISOFREQUENCY_MODE) prepare_isofreq_mode();
                else                                     prepare_edge_mode();
                /* Don't latch mode_prep_done if prep tripped a fault. */
                if (!fault_pending()) g_ctx.mode_prep_done = true;
            }
            if (g_ctx.mode_prep_done) {
                if (g_ctx.mode == EDM_ISOFREQUENCY_MODE) output_run_isofreq(&g_ctx);
                else                                     output_run_edge(&g_ctx);
            }
            break;

        case IDLE:
            output_stage_disable();
            g_ctx.mode_prep_done           = false;
            g_ctx.discharges_since_op_start = 0;
            sleep_ms(10);
            break;

        case STARTUP:
        case FAULT:
            /* STARTUP only persists if boot tripped a fault before we
             * reached IDLE; FAULT is set above and exited via continue. */
            break;
        }

        /* 5. Periodic telemetry. */
        cmd_tick(&g_ctx);
    }

    /* Unreachable. */
    return 0;
}

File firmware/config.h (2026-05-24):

/* config.h
 *
 * Pin assignments, hardware constants, and safe-operating limits for the
 * EPL Wire EDM Power Supply firmware. No runtime state belongs here.
 */

#ifndef EPL_WPS_CONFIG_H
#define EPL_WPS_CONFIG_H

#include <stdint.h>
#include <stdbool.h>

#ifdef __cplusplus
extern "C" {
#endif

/*=============================================================================
 * Pin assignments
 *===========================================================================*/
/* Digital I/O */
static const int EDM_ENABLE_PIN         = 2;    /* Digital input from motion controller */
static const int EDM_FEEDBACK_PIN       = 3;    /* PWM output to motion controller (power ratio) */
static const int OUTPUT_OVERCURRENT_PIN = 12;   /* Active-LOW comparator from output current sensor */
static const int BOOST_PGOOD_PIN        = 18;   /* Active-LOW power-good from boost-converter module */
static const int PMM_FAULT_PIN          = 20;   /* Active-LOW fault from power-management module */
static const int PMM_DIAG_EN_PIN        = 21;   /* Enables PMM fault reporting */
static const int PMM_ENABLE_PIN         = 22;   /* PMM high-side switch enable */
static const int STATUS_LED_PIN         = 25;   /* Onboard LED */

/* Output-stage PWM.
 * SW_HIGH_VOLTAGE_PHASE shares its PWM slice with OUTPUT_OVERCURRENT_SET;
 * SW_ENABLE shares with SW_HIGH_CURRENT_PHASE. P-channel switches invert
 * polarity so HIGH = OFF. */
static const int SW_HIGH_VOLTAGE_PHASE_PIN  = 8;   /* PWM 4A, P-channel (inverted) */
static const int OUTPUT_OVERCURRENT_SET_PIN = 9;   /* PWM 4B */
static const int SW_ENABLE_PIN              = 10;  /* PWM 5A, N-channel */
static const int SW_HIGH_CURRENT_PHASE_PIN  = 11;  /* PWM 5B, P-channel (inverted) */

/* Analog inputs */
static const int PMM_ISENSE_PIN    = 26;   /* PMM current sensor (200 mV/A); ADC channel 0 */
static const int OUTPUT_VSENSE_PIN = 27;   /* Output voltage via 99.6:1 divider; ADC channel 1 */
static const int OUTPUT_ISENSE_PIN = 28;   /* Output current sensor TMCS1133 (25 mV/A); ADC channel 2 */

/* I2C (boost-converter DPOT) */
static const int I2C_SDA_PIN = 16;
static const int I2C_SCL_PIN = 17;

/*=============================================================================
 * Hardware constants
 *===========================================================================*/
#define I2C_PORT             i2c0
#define DPOT_ADDR            0x3E
#define DPOT_REG             0x00
#define I2C_BAUD_RATE_HZ     10000

/* Array-size constants must be #define, not static const, for use in C
 * array declarators and struct definitions. */
#define DEVICE_CURRENT_BUFFER_SIZE  100
#define BOOST_DPOT_POSITION_MAX     110
#define MAX_CMD_PARAMS              4

static const int      ADC_RESOLUTION_BITS = 12;
static const uint32_t PWM_BASE_CLOCK_FREQ = 133000000;  /* 133 MHz */

/* EDM_FEEDBACK encodes input-power ratio as PWM frequency at a fixed
 * 50% duty cycle. Range is narrow on purpose: at MIN the period
 * (5 ms) is shorter than the 10 ms firmware update interval, so the
 * host sees at least two full cycles between updates - resolution
 * traded for responsiveness. See docs/freq-encoding.md. */
static const uint16_t EDM_FEEDBACK_PWM_CLOCK_DIVIDER = 64;
static const float    EDM_FEEDBACK_PWM_DUTY          = 0.5f;
static const uint32_t EDM_FEEDBACK_FREQ_MIN_HZ       = 200;
static const uint32_t EDM_FEEDBACK_FREQ_MAX_HZ       = 400;

/*=============================================================================
 * Sensor scaling
 *===========================================================================*/
static const float ADC_TO_VOLTS                = 3.3f / 4095.0f;
static const float PMM_ISENSE_V_PER_AMP        = 0.200f;      /* PMM current sensor */
static const float ISENSE_OUTPUT_V_PER_AMP     = 0.025f;      /* TMCS1133C1A */
static const int   ISENSE_OUTPUT_AMPS_PER_VOLT = 40;
static const float OUTPUT_VOLTAGE_SCALE        = 0.08090972f; /* (3.3/4095) * 100.4 */

static const int PMM_CALIBRATION_SAMPLES    = 100;
static const int PMM_CALIBRATION_DELAY_MS   = 1;
static const int OUTPUT_CURRENT_SENSOR_CALIBRATION_SAMPLES  = 100;
static const int OUTPUT_CURRENT_SENSOR_CALIBRATION_DELAY_MS = 1;

/*=============================================================================
 * Safe-operating limits
 *===========================================================================*/
static const float MAX_SAFE_INPUT_CURRENT         = 7.3f;   /* A */
static const float MAX_INPUT_POWER_SETPOINT_WATTS = 75.0f;  /* W */
static const float INPUT_SUPPLY_VOLTAGE           = 48.0f;  /* V (nominal) */

static const int MIN_HIGH_VOLTAGE_PHASE_VOLTS = 64;
static const int MAX_HIGH_VOLTAGE_PHASE_VOLTS = 100;

static const int BOOST_DPOT_POSITION_MIN         = 0;
static const int BOOST_CONVERTER_RAMP_SPACING_MS = 10;
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

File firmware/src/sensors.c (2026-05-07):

/* sensors.c
 *
 * ADC sensor implementation. All module state is file-static; the API is
 * a free-function singleton (see sensors.h).
 *
 * ADC channel mapping is positional on the RP2040: GPIO 26..28 → ADC 0..2.
 * `adc_select_input(pin - 26)` is the canonical conversion.
 */

#include "pico/stdlib.h"
#include "hardware/adc.h"

#include "sensors.h"
#include "../config.h"

/* --- Module-static state --------------------------------------------- */

/* Calibration offsets are written by main-loop calibration routines and
 * read by ISR-callable conversion helpers. volatile guards against the
 * compiler caching them across the ISR boundary. */
static volatile int s_pmm_zero_offset       = 0;
static volatile int s_output_current_offset = 0;

/* PMM input-current ring buffer. Single-producer (periodic tick), single-
 * consumer (main loop average). Not ISR-shared. */
static float s_input_current_buf[DEVICE_CURRENT_BUFFER_SIZE];
static int   s_input_current_head  = 0;
static int   s_input_current_count = 0;

/* --- Internal helpers ------------------------------------------------- */

/* Select the ADC mux for a given GPIO and return one fresh sample. */
static inline int sensors_read_pin_adc(int pin)
{
    adc_select_input(pin - 26);
    return (int)adc_read();
}

/* --- Lifecycle -------------------------------------------------------- */

void sensors_init(void)
{
    adc_init();
    adc_gpio_init(PMM_ISENSE_PIN);
    adc_gpio_init(OUTPUT_VSENSE_PIN);
    adc_gpio_init(OUTPUT_ISENSE_PIN);
}

void sensors_calibrate_input_current(void)
{
    long sum = 0;
    for (int i = 0; i < PMM_CALIBRATION_SAMPLES; i++) {
        sum += sensors_read_pin_adc(PMM_ISENSE_PIN);
        sleep_ms(PMM_CALIBRATION_DELAY_MS);
    }
    s_pmm_zero_offset = (int)(sum / PMM_CALIBRATION_SAMPLES);
}

void sensors_calibrate_output_current(void)
{
    long sum = 0;
    for (int i = 0; i < OUTPUT_CURRENT_SENSOR_CALIBRATION_SAMPLES; i++) {
        sum += sensors_read_pin_adc(OUTPUT_ISENSE_PIN);
        sleep_ms(OUTPUT_CURRENT_SENSOR_CALIBRATION_DELAY_MS);
    }
    s_output_current_offset = (int)(sum / OUTPUT_CURRENT_SENSOR_CALIBRATION_SAMPLES);
}

/* --- Slow paths ------------------------------------------------------- */

void sensors_sample_input_current(void)
{
    int adc = sensors_read_pin_adc(PMM_ISENSE_PIN);
    float a = (adc - s_pmm_zero_offset) * ADC_TO_VOLTS / PMM_ISENSE_V_PER_AMP;
    if (a < 0.0f) a = 0.0f;

    s_input_current_buf[s_input_current_head] = a;
    s_input_current_head = (s_input_current_head + 1) % DEVICE_CURRENT_BUFFER_SIZE;
    if (s_input_current_count < DEVICE_CURRENT_BUFFER_SIZE)
        s_input_current_count++;
}

float sensors_avg_input_current_amps(void)
{
    if (s_input_current_count == 0)
        return 0.0f;

    float sum = 0.0f;
    for (int i = 0; i < s_input_current_count; i++)
        sum += s_input_current_buf[i];
    return sum / (float)s_input_current_count;
}

float sensors_read_output_voltage_averaged(int samples)
{
    if (samples <= 0)
        return 0.0f;

    float sum = 0.0f;
    for (int i = 0; i < samples; i++)
        sum += sensors_read_pin_adc(OUTPUT_VSENSE_PIN) * OUTPUT_VOLTAGE_SCALE;
    return sum / (float)samples;
}

/* --- ISR fast paths --------------------------------------------------- */

int sensors_read_output_current_adc(void)
{
    return sensors_read_pin_adc(OUTPUT_ISENSE_PIN);
}

int sensors_read_output_voltage_adc(void)
{
    return sensors_read_pin_adc(OUTPUT_VSENSE_PIN);
}

float sensors_adc_to_discharge_current_amps(int adc)
{
    float a = (adc - s_output_current_offset) * ADC_TO_VOLTS * (float)ISENSE_OUTPUT_AMPS_PER_VOLT;
    return a < 0.0f ? 0.0f : a;
}

float sensors_adc_to_discharge_voltage_volts(int adc)
{
    float v = adc * OUTPUT_VOLTAGE_SCALE;
    return v < 0.0f ? 0.0f : v;
}

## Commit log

2026-04-11 begin firmware reworks with new project structure
    [boost_module.cpp, config.h]
2026-04-21 fix: resolve baseline compile errors and latent bugs in firmware.ino
    - close READ_HVP_VOLTAGE() function body; missing brace caused every
    subsequent function to be parsed as nested, breaking the build
    - pass BOOST_PGOOD pin (not the BOOST_CONVERTER_PGOOD_FAULT enum value)
    to gpio_acknowledge_irq/gpio_get in the HV fault handler
    - rename global FaultStateType variable to currentFaultType so it no
    longer shadows the enum of the same name
    - drop isInFaultState (never assigned); telemetry now checks
    deviceState == FAULT directly so the fault type actually prints
2026-04-21 refactor: extract pin map and shared types into config.h and src/types.h
    firmware.ino no longer declares pins, safe-operating limits, sensor
    scaling, or enum/struct definitions — all moved behind include guards.
    Names are preserved verbatim so call sites are untouched; naming-
    convention cleanup comes with the module split.
    Also drop the duplicate peripheralManagementInterval_MS and inrushDelay_MS
    variables; the config.h constants (PMM_INRUSH_DELAY_MS,
    peripheralManagementInterval_MS) replace them.
    [config.h]
2026-04-26 implementing boost converter struct for api, adding calibration system for dpot. todo:make cal table private
2026-04-26 update sensor functions, new implementation
2026-04-27 working on sensor module, warning: currently broken
    [config.h]
2026-04-28 Revert "working on sensor module, warning: currently broken"
    This reverts commit 1827d26e5842b240438f25bb21ef2ef30b65d1c3.
    [config.h]
2026-04-28 Revert "Revert "working on sensor module, warning: currently broken"" Bring refactor branch back to compiling/running state
    This reverts commit 237029e37f75e89845acd283399535b34020cad1.
    [config.h]
2026-04-30 add output stage handling to voltage table initialization in setup()
2026-04-30 update PIN constant names, add print statements for boost converter setup sequence
2026-05-07 new src, library style implementation, removed dependancy on arduino-pico and rely on pico-sdk only.
2026-05-07 replace firmware.ino with main.c, add pico-sdk based build system and new config
    [config.h, main.c]
2026-05-07 add low-voltage error check for HVP
    [main.c]
2026-05-24 encode edm_feedback as pwm frequency instead of duty cycle
    The motion controller (Mesa 7i76eu) consumes the EDM_FEEDBACK line via
    its encoder inputs. Encoder counters natively measure frequency, so a
    duty-cycle-encoded signal requires extra processing on the host side
    and doesn't fit the traditional CNC tooling. Encoding the power ratio
    as PWM frequency at a fixed 50% duty makes the signal trivially
    readable by any CNC controller with a pulse-counting input.
    The power ratio carried on this line is the sparking-success-rate
    proxy, used by the host as the plant variable for closed-loop feedrate
    scaling: the CNC speeds up when sparks are sparse and slows down when
    they're dense, so the gap sta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
    [config.h, fault.c, main.c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]
2026-05-24 narrow edm_feedback band to 200..400 Hz, document encoding
    At the prior 50..500 Hz range the low end of the band has a 20 ms
    period, longer than the 10 ms firmware update interval - each new
    ratio sample would smear across multiple host servo-thread reads
    before the next firmware tick landed, defeating the point of updating
    at 100 Hz. Narrowing to 200..400 Hz puts the slowest cycle (5 ms) at
    half the update interval, so the host sees at least two complete
    cycles per update. Trades ratio resolution for transport
    responsiveness, which is the correct trade for a feedrate-scaling
    control variable.
    Adds docs/freq-encoding.md with the full picture: what's transmitted
    (input-power ratio, with note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
    [config.h]
2026-09-27 bring up to date
    [0679H9120-05.step, 0906-8-15-20-76-14-11-0.step, 226TTA350M.step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]
2026-09-27 update decals
    [buck-converter.kicad_sch, controller.kicad_sch, dual-converter-boost-converter-module-V1.0.kicad_pcb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]

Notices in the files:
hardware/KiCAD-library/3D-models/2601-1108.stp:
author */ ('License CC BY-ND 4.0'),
